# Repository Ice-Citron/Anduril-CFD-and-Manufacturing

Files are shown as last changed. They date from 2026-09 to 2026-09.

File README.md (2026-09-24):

# Anduril CFD and Manufacturing

**[ANDÚRIL RACING — Official team website](https://andurilracing.com/)**

[My personal commentary and project experience](https://sienarindustries.com/project/f1-in-schools)

Car designs, CAD exports, and supporting models for team ANDÚRIL RACING from Marlborough College Malaysia.

## Start here

These are the two main documents for this project. Read the project portfolio first.

1. [Project portfolio](PROJECT_PORTFOLIO.pdf) — Explains our contributions, design decisions, and build process. It covers the car and the wider team project.
2. [Technical drawings and renders](DRAWINGS_AND_RENDERS.pdf) — Shows the assembled car, dimensioned component drawings, and final renders.

*Louis Gan and Shi Hao Ng produced the project portfolio in Adobe Illustrator.*

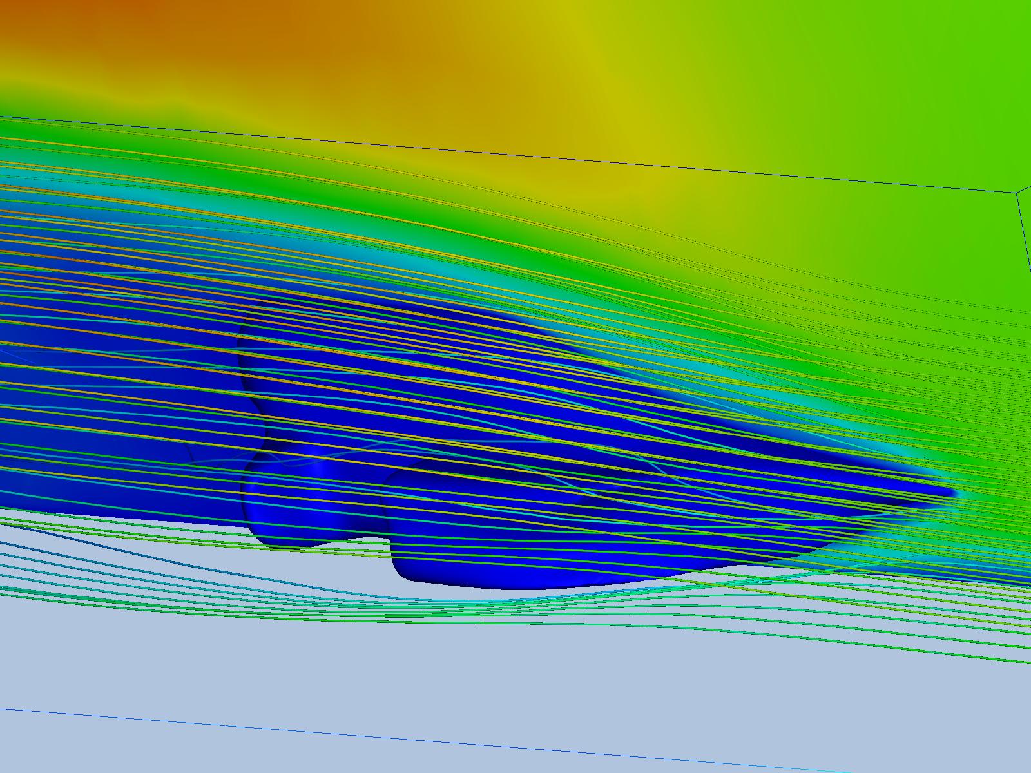
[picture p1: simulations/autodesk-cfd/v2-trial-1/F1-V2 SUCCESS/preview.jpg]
Airflow around the Version 2 car in Autodesk CFD


*Saved airflow visualisation from the Version 2 Autodesk CFD study.*

## About this repository

This repository contains the simulation and manufacture files for our F1 in Schools car. It follows the work from early geometry preparation to the Version 5 production exports.

The files cover three parts of the project:

- Computational fluid dynamics (CFD) studies.
- Geometry repair and conversion.
- Exports for CNC manufacture and resin print production.

The [Anduril Design repository](https://github.com/Ice-Citron/Anduril-Design) contains the wider design history. This includes the original Blender models and concept sketches.

## From a design to a physical car

Our team started with car models in Blender. We then prepared these models for CFD and manufacture.

This required several steps. We exported STL geometry from Blender and converted it to STEP format through Fusion 360. We used Ansys Discovery to prepare geometry for Fluent. More complex revisions also required mesh repair in Autodesk Netfabb.

The CFD work helped us examine airflow around the wheels and behind the car. We used these observations to develop the body shape and rear vanes.

Manufacture introduced further constraints. We had to consider component strength and the material available for the car body. The final work included separate exports for the CNC body and resin wings.

The project portfolio explains these decisions and the changes between car versions.

## CFD studies

The repository contains work from Autodesk CFD and Ansys Fluent.

| Study | Contents |
|---|---|
| [Version 2 Autodesk CFD trial](simulations/autodesk-cfd/v2-trial-1/) | Native project files, solver records, and saved output. Includes the airflow image above. |
| [Version 2 Fluent preparation](simulations/ansys-fluent/v2-preparation/) | Geometry exports and a Fluent session transcript. |
| [Version 2 UoSM study](simulations/ansys-fluent/v2-uosm-study/) | Ansys Discovery geometry, mesh files, and saved Fluent case and solution files. |

### Autodesk CFD

The Version 2 trial contains an Autodesk CFD 2024 project and its support files.

The main project is:

[Open the Autodesk CFD project file](<simulations/autodesk-cfd/v2-trial-1/F1-V2 SUCCESS/F1-V2 SUCCESS.cfdst>)

Its scenario folder contains mesh records and solver output. The saved preview provides a quick view of the airflow around the car.

### Ansys Fluent

The preparation folder records an early Fluent 2024 R1 session. It contains geometry preparation files rather than a saved case and solution pair.

The UoSM study contains the more complete simulation files:

- [Ansys Discovery model](simulations/ansys-fluent/v2-uosm-study/Discovery_File.dsco)
- [Mesh exports and workflow files](simulations/ansys-fluent/v2-uosm-study/Export/)
- [Fluent case and solution folder](<simulations/ansys-fluent/v2-uosm-study/Fluent/UoRM - Hypothesis/>)

The Fluent folder includes:

- `FSAE_Solution_Final.cas.h5`
- `FSAE_Solution_Final.dat.h5`

Earlier mesh attempts remain beside the later exports. These files show the geometry preparation work behind the study.

Some project files contain original Windows paths. You may need to update these paths in the relevant application.

## Geometry development

The `geometry/` folder contains intermediate models and exports for further analysis or manufacture.

| Folder | Contents |
|---|---|
| [Component variants: 2 mm](geometry/components-2mm/) | Rear-wing STL and OBJ files. |
| [Component variants: 3 mm](geometry/components-3mm/) | Wing and reference component meshes, including repaired exports. |
| [Version 3, trial 1](geometry/v3-trial-1/) | Three STL revisions from the Version 3 design. |
| [Version 4](geometry/v4/) | Body and component revisions, Netfabb projects, and STEP geometry. |
| [Version 5 CFD geometry](geometry/v5-cfd/) | STEP exports for the single-vane and double-vane configurations. |

The Version 5 comparison models are:

- [2 mm double-vane model](<geometry/v5-cfd/Version 5 - CFD 2mm double v0.step>)
- [3 mm single-vane model](<geometry/v5-cfd/Version 5 - CFD 3mm single v3.step>)

The internal filenames preserve the original revision labels.

## Manufacture

The `manufacturing/` folder contains files prepared for external suppliers and resin print production.

| Folder | Contents |
|---|---|
| [Version 4 CNC preparation](manufacturing/cnc/v4-fiverr/) | Body meshes and STEP exports from the earlier supplier work. |
| [Version 5 CNC exports](manufacturing/cnc/v5-fauzi-larkins/) | The Version 5 CNC STEP model and a body STL check export. |
| [Version 5 resin print exports](manufacturing/resin-print/v5/) | Body and wing STL files, including separate front-wing and rear-wing models. |

[View the Version 5 CNC model](<manufacturing/cnc/v5-fauzi-larkins/Version 5 - CNC v5.step>)

Nosco Asia helped us work with a CNC supplier in Larkin, Johor Bahru. Our team supported the CAM preparation through Mastercam and Fusion 360.

The University of Southampton Malaysia provided resin print facilities for the front and rear wings. The project portfolio records the subsequent assembly and surface finish work.

## My contribution and the team

I am Shi Hao Ng. I was the project manager and general engineer for ANDÚRIL RACING.

I led the technical work on CFD and car design. I also coordinated external support and managed the track manufacture work.

This was a team project. The portfolio records the following roles:

| Team member | Main responsibilities |
|---|---|
| Shi Hao Ng | Project management, technical direction for CFD and car design, and track manufacture coordination. |
| Louis Gan | Electronics, the track timer system, and graphic design. |
| Samson Hong | CAD models, car manufacture, and Blender renders and animation. |
| Jolie Teo | The team website, graphics, and support for manufacture and sponsorship. |
| Hengjun Tian | Ansys Fluent studies and track manufacture. |
| Jane Ng | Car concept art and sponsor relations. |

The University of Southampton Malaysia supported the CFD work and resin production. Nosco Asia supported CNC manufacture. Marlborough College Malaysia supported the wider project and track construction.

## Repository structure

```text
Anduril-CFD-and-Manufacturing/
├── README.md
├── PROJECT_PORTFOLIO.pdf
├── DRAWINGS_AND_RENDERS.pdf
├── LICENSE
├── simulations/
│   ├── autodesk-cfd/
│   │   └── v2-trial-1/
│   └── ansys-fluent/
│       ├── v2-preparation/
│       └── v2-uosm-study/
├── geometry/
│   ├── components-2mm/
│   ├── components-3mm/
│   ├── v3-trial-1/
│   ├── v4/
│   └── v5-cfd/
└── manufacturing/
    ├── cnc/
    │   ├── v4-fiverr/
    │   └── v5-fauzi-larkins/
    └── resin-print/
        └── v5/
```

## Related repositories

- [Anduril](https://github.com/Ice-Citron/anduril) — Main project repository, team website source, and sponsorship documents.
- [Anduril Design](https://github.com/Ice-Citron/Anduril-Design) — Original design files, concept sketches, and models for the car and track.

## Licence

This repository uses the [MIT License](LICENSE).

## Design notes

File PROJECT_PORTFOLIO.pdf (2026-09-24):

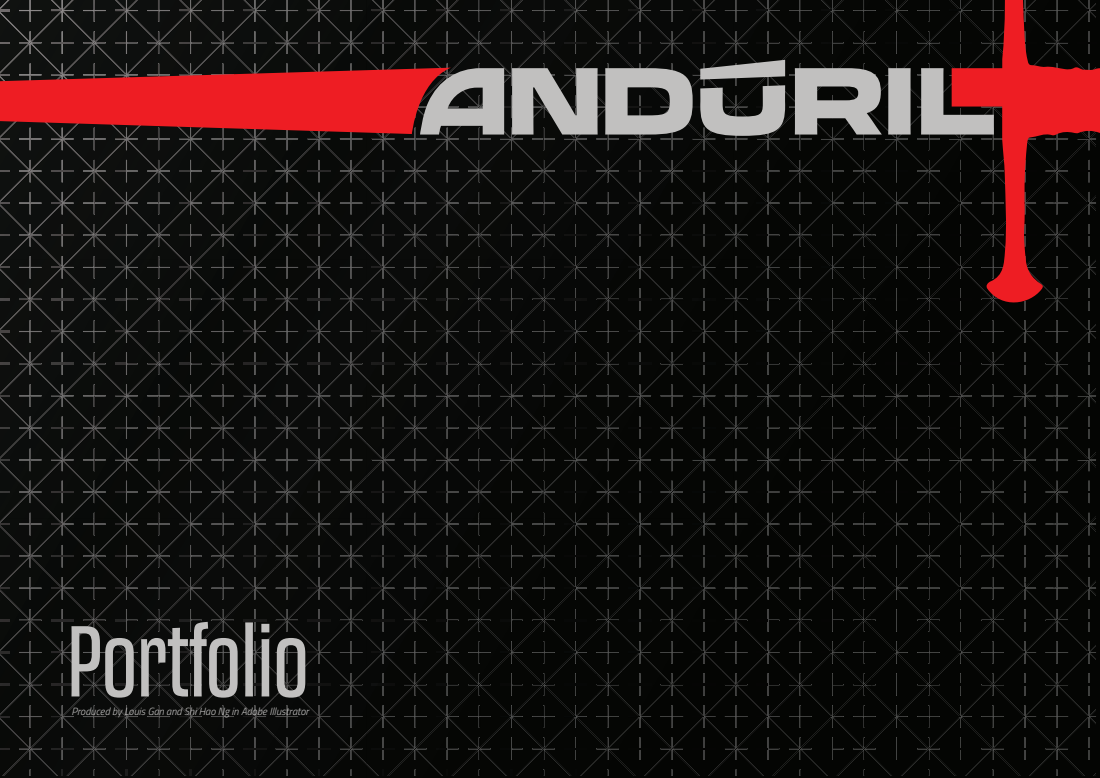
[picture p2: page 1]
Portfolio

Produced by Louis Gan and Shi Hao Ng in Adobe Illustrator

# Research and Development Workflow

Our journey began with Samson and Jane crafting the initial car designs using Blender. Although Blender is primarily an animation software, we chose it for our main CAD modeling due to our team's familiarity with the platform and its ease in translating our concept art into 3D models. These early versions (v1 & v2) were rich in creativity and aesthetics but lacked consideration for the competition's no-go zones and model block size specifications.

# 1 Sketches

With our initial models ready, we proceeded to CFD testing using Ansys Fluent, assisted by University of Southampton Malaysia. Since CFD software requires meshable models, we exported our Blender designs as STL files and converted them to STEP files using the T-Spline function in Fusion 360. These STEP files were then imported into Ansys Discovery for preparation before running simulations in Ansys Fluent. The simulations applied an inlet velocity of 30 m/s and an angular velocity of 2000 rad/s for all 4 wheels to mimic race conditions.

In Version 4, we maintained the long tail design but became more rigorous with regulatory compliance. To meet the no-go zone regulations, we adjusted the entire car forward, allowing us to retain the tail at the car's end while complying with the rules. We meticulously ensured that all aspects of the car met the regulatory requirements.

However, we strategically decided to accept a 5-point penalty related to the front wing chord length (Rule D7.9). Redesigning the front section to comply fully would have resulted in a structurally weaker and less aesthetically pleasing front wing. We deemed the penalty acceptable to maintain the integrity and performance of our design. Most importantly, we ensured that the front wing did not obstruct any other components of the car (e.g. main body).
Due to the increased complexity of Version 4 compared to Version 2, we needed to remesh the STL file using Autodesk Netfabb before converting it to a STEP file with Fusion 360's T-Spline function.

The analysis revealed several weaknesses:
1. Airflow into Wheels: Contour path lines indicated that airflow tended to enter the wheels, creating significant drag. Our per-component analysis showed that the front wing contributed to 70% of the total drag (47.68 mN). Additionally, the wheels, spinning at 2000 rad/s, exacerbated drag due to air bouncing around them.
2. Iso-Pressure Zones: These zones indicated inefficiencies in airflow around the car body, particularly due to the wake of the car. Notable iso-pressure zones were observed behind the front wing, behind the front wheels, and especially at the rear of the car.

Iso-Pressure Zones: These zones (graphed out in image above) indicated inefficiencies in airflow around the car body, particularly due to the wake of the car. Notable iso-pressure zones were observed behind the front wing, behind the front wheels, and especially at the rear of the car.

# 2 Transition to CFD Analysis

# 3 Design Iterations: Version 3

We also introduced air vanes (diverters) to direct airflow to the low-pressure recirculation zone in the rear middle of the car, further minimising turbulence. Concept art for Version 3 was created, showcasing the long tail design and the coverage of both front and rear wheels as much as regulations allowed. We then utilised this concept art directly within Blender to assist in the modelling process.

To address these issues, we focused on minimising the wheels' exposure to airflow. Inspired by the tail design of the McLaren Speedtail, we incorporated a longer tail with a gradual slope behind the rear wheels. This aimed to even out the airflow, reducing turbulence by allowing air to fill the area more gradually, thereby reducing iso-pressure zones at the rear.

Using concept art within Blender to assist in modelling

# 3 Adhering to Regulations: Version 3 Onwards

From Version 3 onwards, we began factoring in the actual model block and no-go zones as specified by the competition rules. We ensured that the front wheels were covered up to a maximum of 20 mm from the bottom of the track and maintained a 3 mm exclusion zone around the wheels, as per the regulations.

To meet no-go zone regulations, we pushed the entire car forward to retain the tail

# Manufacturing

To save money for our school from buying the official expensive Denford Webshop equipments. We took on the ambitious task of manufacturing our own gas launcher, track timer system, and a 20-meter racing track to simulate race conditions accurately.

Our gas launcher was 3D-printed using PLA material, following a design courtesy of @TeachingTech on Printables.com. Key features of the gas launcher include:
- High-Tension Springs: Ensure rapid activation and consistent propulsion of the car.
- Sharpened Screw: Acts as a puncture mechanism for the CO₂ canisters.
- Electric Solenoid Integration: Allows for electronic control through the press of a button, providing precise timing and synchronisation with the timing system (mimicking the official Denford system). After assembly and testing, the gas launcher performed successfully, meeting our requirements for race simulations.

# Gas Launcher

Once the main body and front wing are finalised, we worked on the rear wing. The rear wing was designed primarily for aesthetic purposes and to comply with competition regulations, as additional downforce was unnecessary for a straight-line race. The rear wing features a flat profile cross-section and complements the overall design of the car.
Finally, we sent our finalised design files to Nosco Asia for CNC machining. Concurrently, we used resin printers at UoSM to produce components like the front and rear wings.

We constructed a 20-metre track using pine wood through the following steps:
1. Design: Sketched and designed the track layout in Blender for ease of manufacturing and coordination with the Estates team.
2. Cutting & Sanding: Cut pine wood to required dimensions using a jigsaw and table saw, then sanded with orbital sanders while wearing safety goggles and aprons.
3. Track Connectors: Fabricated joints by modifying stainless steel brackets to securely connect track segments, ensuring safety gear was worn.
4. Assembly: Applied adhesive to join track sections and collaborated with Marlborough College Malaysia’s Estates team to carry and assemble the track and tables.
With assistance from the Estates team, we assembled the track and tables in our designated testing area, repurposing unused old tables from MCM to promote sustainability.
Finishing Touches
We painted the pinewood track to enhance its appearance and protect against Malaysia's humid conditions. Custom decals were added to personalize the track and promote our team branding.

# 20m Track

To accurately measure the performance of our car, our Electronics Engineer prefabricated a track timer system using an Arduino microcontroller paired with laser sensors and photoreceptors. The system was programmed in C++, enabling precise detection of the car's start and finish times, thus allowing us to gather essential data on speed and acceleration.

# Track Timer System

Nosco Asia facilitated our collaboration with a third-party CNC machining service in Larkin, Johor Bahru. Working closely with their team, we built the CAM file based on the STEP file of our final car design.

- CNC Machining: Precisely
cutting the car's body from
the specified material using computer-controlled
equipment. We’ve assisted
the 3rd party provider
“Sticker Shop@Larkins, JB” with Mastercam and
Fusion 360. To guide him
with the process of
machining our car.
- Sanding: Post-machining, we sanded the car's
surface to eliminate any
rough edges or
imperfections.

# 4 Car Manufacturing Final CFD Testing and Improvements

We conducted further CFD tests using the same setup as before. The results showed a significant reduction in drag:
- Version 2 Drag: 47.68 mN
- Version 4 Drag: 29.52 mN (single vane diffuser)
- Version 4 Drag: 30.36 mN (double vane diffuser)
These CFDs conducted using the Comsol fluid modulus indicate a substantial reduction in turbulence. The side profile of the air velocity graphs confirmed that our design modifications effectively minimised turbulence compared to Version 2.

Initially, we designed a triple vane rear diffuser, but material constraints and potential airflow disruptions limited us to single and double vane configurations. A double vane design required vanes only 20mm thick, risking breakage with our polyurethane car body. To mitigate this, we opted for a single vane diffuser with a 30mm thickness for Version 5. Once the design was finalized, we prepared the files for CNC machining and began designing the rear wing.

Cross-sectional profile of Rear Wing

<--- Final Version 5 car with rear wing

Mastercam software. We guided the 3rd party Nosco Asia’s CNC provider over Whatsapp on how to CNC our car, and the
requirements.
- 3D printed front wing: We’ve used the resin printers of University of Southampton to facilitate the printing of our front wings and rear wings.
- Assembly: We’ve used adhesives to attach components such as the front and rear wings.
- Final Painting and Sticker: The car is then spray painted to metallic black. However, applying the sticker will be an outstanding task, as of 2/10/2024. But we will be applying our team colours and sponsorship stickers to align with our branding.
Through this meticulous process, we aimed to produce a car that not only meets the competition's technical specifications but also embodies our team's dedication to excellence in engineering and aesthetics.

Priming and Painting: To prepare the car for painting, we applied six layers of primer, meticulously alternating between spraying and sanding each layer. This iterative process ensured a smooth surface that minimizes the drag coefficient, providing an ideal foundation for the final paint.

# Team Roles & Responsibilities

Project Management
Effective communication and coordination are the backbone of our project management strategy. While each team member has clearly defined roles, flexibility is maintained as members step into different responsibilities when needed to ensure smooth progress and efficiency.
Google Drive: Acts as our centralized repository for all documents, facilitating real-time collaboration and easy access for every team member.
GitHub: Utilized for storing larger files such as CAD models and website code, ensuring robust version control and seamless updates.
Emails: Serve as the primary method for assigning tasks, sharing detailed information, and communicating daily goals. Instant Messaging (Instagram Messages): Preferred during holidays for quick communication. During regular school days, we alternate between Instagram messages and emails based on accessibility and convenience.
Instagram Calls: Employed for emergency meetings and real-time collaboration, especially when team members are working remotely.

Name Background
Our team name, Andúril, is inspired by the legendary sword from The Lord of the Rings. Reforged from the shards of Narsil, Andúril symbolises hope, renewal, and leadership in times of adversity. It serves as a powerful emblem of unity and strength, reflecting our team’s commitment to overcoming challenges and striving for excellence.
Colours
We selected a palette of red, silver, and black to represent our team:
Red: Symbolises passion, energy, and speed, embodying the core values of Formula 1. Silver: Represents precision, technical excellence, and innovation, highlighting our engineering prowess.
Black: Adds contrast and sophistication, enhancing the overall aesthetic of our design. These colours were chosen based on extensive research and a team-wide questionnaire, ensuring they resonate well with our brand and are visually appealing. Team Motto
"Per Aspera Ad Astra"
Our team’s motto, "Per Aspera Ad Astra," embodies the essence of our journey and aspirations in the F1 in Schools competition. This Latin phrase translates to "Through Hardships to the Stars," reflecting our commitment to overcoming challenges and striving for excellence in every aspect of our project.
Uniform
Our team uniforms are designed to showcase both unity and our brand identity. Key considerations in the design include:
Clear and Memorable Branding: Ensures our team is easily identifiable. Professional Appearance: Reflects our values of excellence and dedication. Strategic Placement of Sponsor Logos: Guarantees visibility and return on investment for our sponsors. Comfort and Suitability: Designed to be worn comfortably in Malaysia’s humid climate, ensuring team members can perform optimally.

Gantt Charts (Google Sheets): Used to outline task expectations and deadlines, providing a clear timeline and efficient progress tracking. Our Gantt Charts include:
Job Descriptions: Clearly define each task and responsibility.
Job Status: Track the progress of each task.
Time Remaining: Monitor deadlines to ensure timely completion. Potential Safety Risks: Identify necessary Personal Protective Equipment (PPE) for each task. Risk of Timeline Delays: Assess the likelihood of delays and prepare backup plans. For example, on October 2, 2024, when Jolie fell ill last minute, causing a portfolio submission delay, we activated our backup plan by adjusting our schedule the following day to accommodate the change.
Expense Tracking (Excel Sheets): Managed all expenses and finances using Excel sheets, ensuring transparent and accurate financial oversight.

In-Person
Meetings:
Conducted for
group work and
tackling complex
tasks, leveraging
the productivity
and clarity of
face-to-face
interactions.

### Our team, Andúril Racing, is composed of six dedicated members, each bringing unique skills to the table:

### Shi Hao Ng: Project Manager & General Engineer –

Oversees project coordination with all stakeholders,

### technical lead for CFD and car design, and manages

track manufacturing tasks.

### Louis Gan: Electronics Engineer & Lead Graphic Designer – Designer for brand identity such as logos, merchandise and banners, and develops

electronic systems for testing the car.

### Samson Hong: Design Engineer – Leads the car manufacturing and CAD modelling process, and

ensures high quality Blender animation & rendering.

### Jolie Teo: Web Designer & Graphics Designer – Develops and maintains our team’s website and creates graphics materials, also assisting in

manufacturing and sponsorships.

### Hengjun Tian: CFD Engineer & Manufacturer – Conducts Computational Fluid Dynamics (CFD) with Ansys Fluent and implements the track

manufacturing process.

### Jane Ng: Concept Artist & Sponsorship Manager – Creates concept art for car and manages

sponsorship outreach and relationships.

# About Us

Emails: The project manager often Team Identity reaches out to teammates to

distribute work and to communicate
what each member should get done
for the day.
We purchased custom email domains for our team for a streamlined electronic mail experience as well as a professional look when sending sponsorship requests via email. Typography
Our chosen font, Transducer Extended Bold, conveys
confidence and power. Its
streamlined design mirrors the sleek form of Formula 1 cars, emphasising precision and high-tech performance. The metallic texture of the font enhances its high-tech, engineered aesthetic,
aligning seamlessly with the advanced dynamics of
racing.
The Andúril logo features
the team name seamlessly
integrated along a sword
blade, symbolising the unity between our team and its
legendary inspiration.

# Partnership and Sponsorship

Our partnership with the University of Southampton Malaysia allowed us to use their program “Ansys Fluent” to test our F1 in car’s model’s movement and design. Their research assistance not only helped us save funds but also time. They had also provided us with resin printing equipment, which helped our production of the actual car.

## Return on Investment

We have laid a strong foundation for future participants in F1 in Schools, not just at MCM, but in Johor. By building our own track, gas launcher and electronics timer system, we saved the school approximatelyMYR 42,000, excluding 30% import duties and taxes. Considering their sponsorship of just MYR 6,000, this is a substantial return on investment for Marlborough College Malaysia. Most importantly, we firmly believe that, because of us, because of our manufacturing of the track, gas launcher, and track timer system. We had laid out a
strong foundation for many future teams from MCM
to join the F1 in Schools programme.

Nosco Asia Sdn Bhd played a crucial role in our manufacturing and marketing strategies. They facilitated our collaboration with a CNC machining service in Larkin, Johor Bahru, ensuring precise production of our car components. Nosco Asia also provided banner printing services and transportation support, which significantly boosted our marketing efforts and outreach campaigns. They had sponsored us 3,200 MYR for the banner printing and the CNC machining services.

We worked on the business aspects with UoRM and most of these include the sponsorship proposal. Although our sponsorship proposal wasn’t as successful as we wished for it to be (as we only managed to receive Nosco Asia’s support), we wish to flesh it out further and try out a different technique for the nationals. They had also helped us with project management after advising our project manager to try “Gantt Chart” to distribute tasks and communicate deadlines; and dealing with issues such as conflict between team members; also when we were forced to remove a member due to the severe lack of contribution.

Our school, Marlborough College Malaysia (MCM), has been our main sponsor for all of our respective expenses of up to 6k MYR. MCM supported us in many different ways, including providing old desks for our track, allocating estate staff to assist in track manufacturing and moving equipment from one building to another. MCM also allowed us to display banners across the school to advertise. In return, we built a race track and an efficient timing system which is open to any schools established in Johor (to encourage new F1 in schools participants in Johor). Additionally, by reusing desks that were set to be scrapped, we contributed to reducing waste and reusing materials.

To enhance our design's aerodynamic efficiency, we attended courses with Professor Azam Bakir at the University of Southampton Malaysia (UoSM). These sessions provided a foundational understanding of the Navier-Stokes equations and fluid dynamics principles. Recognizing that solving Computational Fluid Dynamics (CFD) simulations analytically is impractical for complex designs, we agreed with Professor Bakir's assessment to focus on computational methods and fluid flow theories. Concepts such as how holes lead to suction and how low-pressure zones lead to turbulence became central to our design considerations.

YOUR
LOGO
HERE

AD
PLACE
MENT

COMPANY
PARTNERSHIP

YOUR
LOGO
HERE

AD
PLACE
MENT

COMPANY
PARTNERSHIP

We have also created a website summarising details regarding our team members, summarising our sponsors and answering any questions regarding F1 in schools and our team.
We felt that creating a website can create memorable credentials with companies and schools who may wish to sponsor us but are confused as to what Anduril Racing stands for.

Our social media endeavours ranged from Instagram, later to Linkedin (to establish a professional identity for Anduril Racing) and lastly, Facebook. Our strategy begins with reaching out to familiar faces : we followed familiar people such as our family members, then our relatives, schoolmates and lastly, accounts that are associated with f1. We can help to build awareness on Anduril Racing’s participation in F1 in schools and hence potentially gain partnerships. Social media was also a great way of allowing our partners to keep track of Anduril Racing’s activities and recent goals.

To advertise Anduril Racing, three of our members went on to hike Mount KInabalu and spread the word regarding Anduril Racing’s participation in the competition (to different hikers that we met along the way). Many of our fellow hikers still check on our Instagram till this day.

# ခandurilracing.com

## Mount Kinabalu Teambuilding & Mountain Climbing Trip (4095m)

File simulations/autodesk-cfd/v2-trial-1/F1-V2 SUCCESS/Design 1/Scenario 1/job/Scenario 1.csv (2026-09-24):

CPU time | 35.804
memory | 200450048
fluid nodes | 74332
solid nodes | 9256
fluid elements | 211266
solid elements | 75956

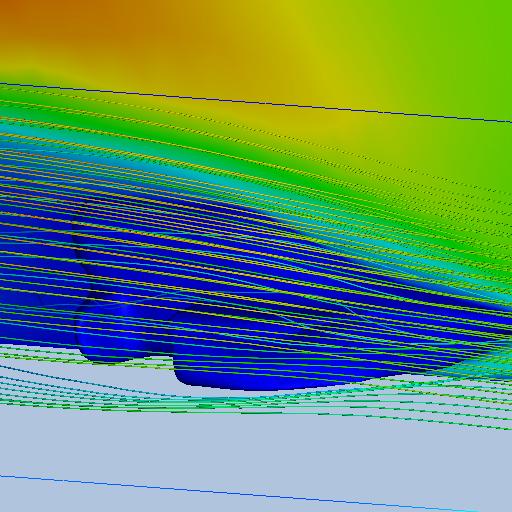
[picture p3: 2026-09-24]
simulations/autodesk-cfd/v2-trial-1/F1-V2 SUCCESS/Design 1/Scenario 1/thumbnail.jpg

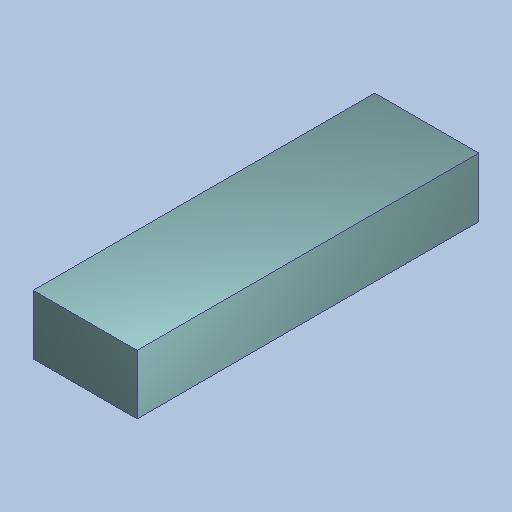
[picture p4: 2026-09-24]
simulations/autodesk-cfd/v2-trial-1/F1-V2 SUCCESS_support/Design 1/Scenario 1/thumbnail.jpg

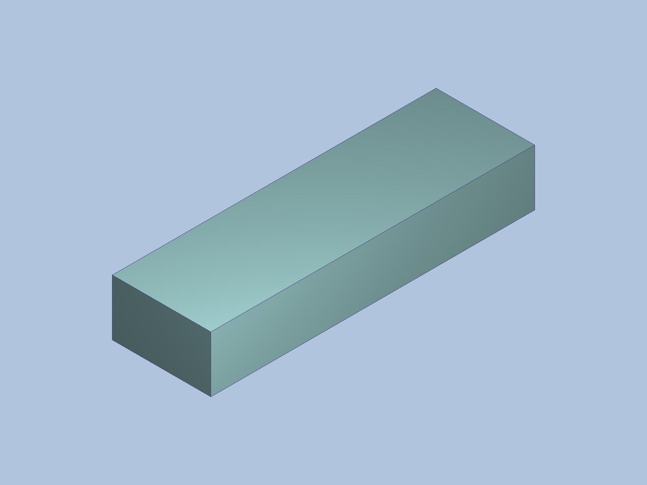
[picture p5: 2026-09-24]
simulations/autodesk-cfd/v2-trial-1/F1-V2 SUCCESS_support/preview.jpg

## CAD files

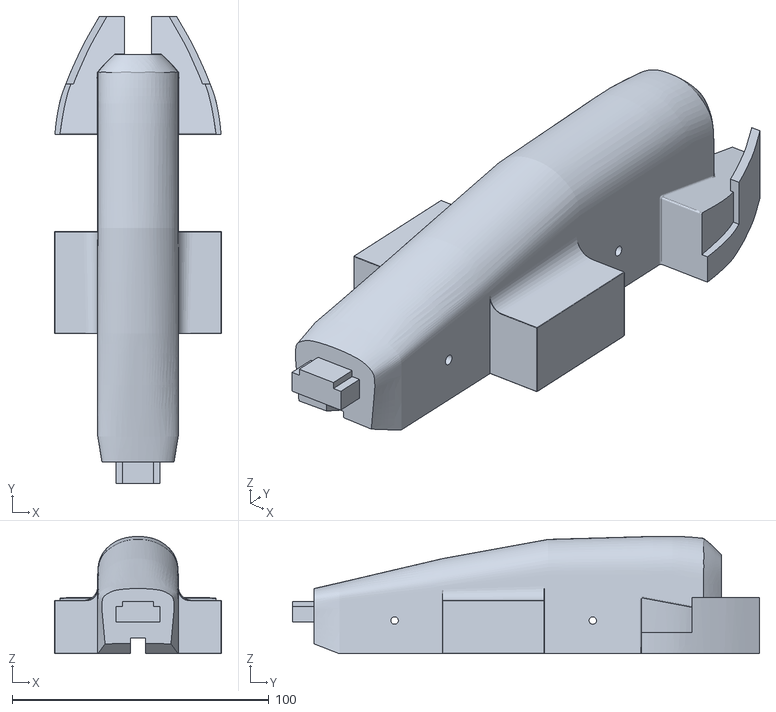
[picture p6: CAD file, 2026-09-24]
manufacturing/resin-print/v5/MAIN_Body1.stl
65.0 x 181.9 x 45.6

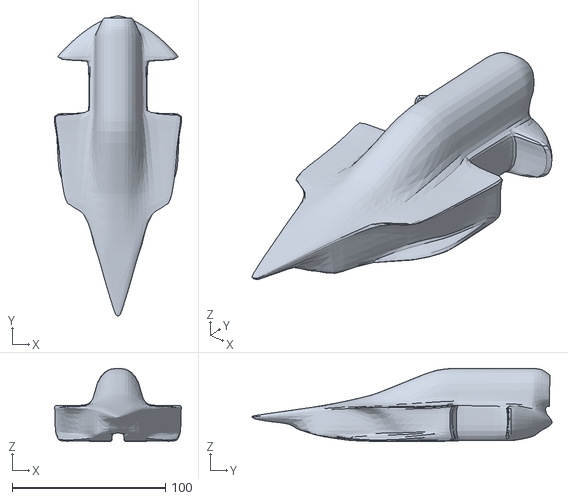
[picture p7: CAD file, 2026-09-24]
simulations/autodesk-cfd/v2-trial-1/Ver-2-new-ASSEMBLE BODY.stl
83.0 x 195.8 x 47.7

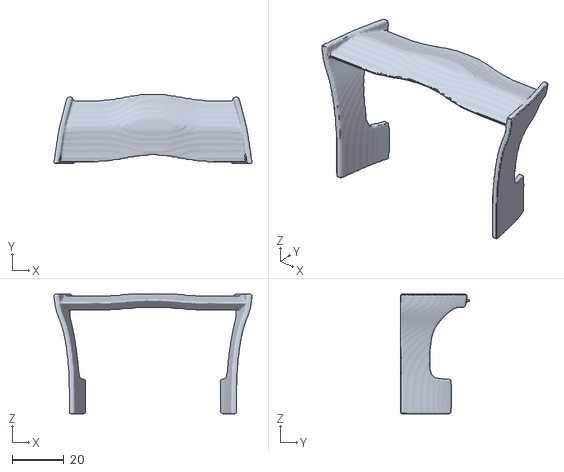
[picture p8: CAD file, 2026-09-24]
geometry/components-2mm/2mm - Blueprint and STL-Rear Wing - flaps.005 (manipulated).obj
76.8 x 26.9 x 46.5

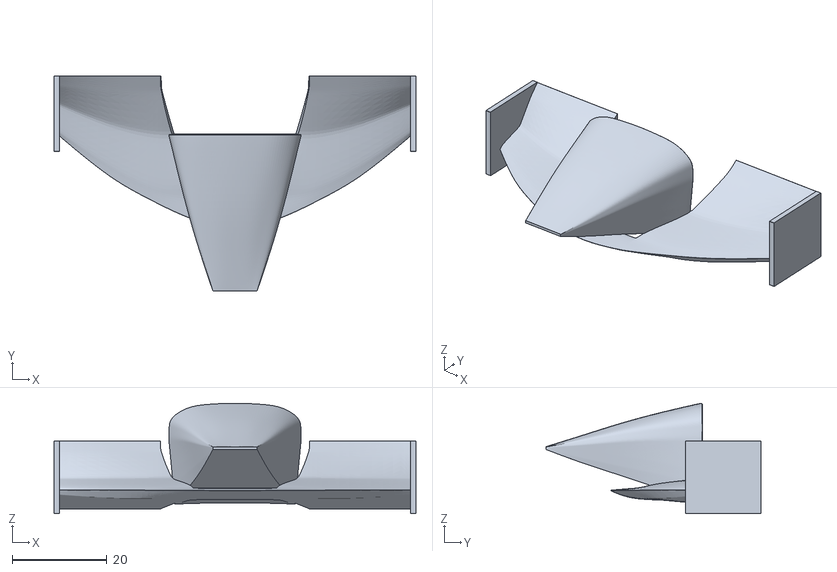
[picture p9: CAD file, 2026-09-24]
geometry/components-3mm/Blueprint and STL-FRONT WING Version 3.008.stl
76.5 x 45.5 x 23.3

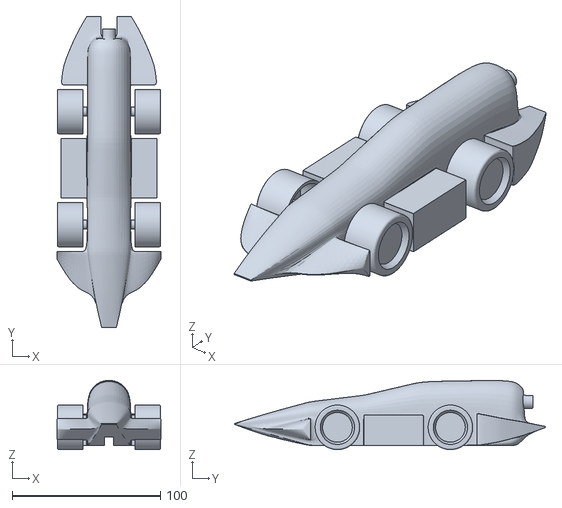
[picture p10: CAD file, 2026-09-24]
geometry/v3-trial-1/Version 3 - Louis-Version 3.006.stl
70.3 x 209.5 x 46.6

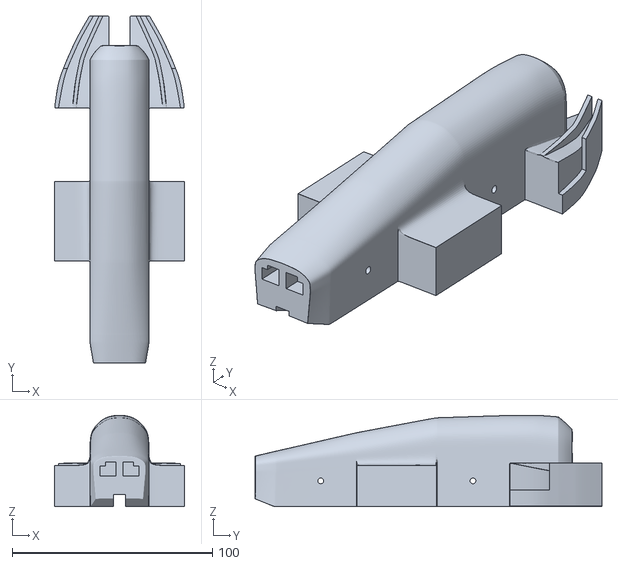
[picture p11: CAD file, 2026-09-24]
geometry/v4/AAA - MAIN STEP CNC/Version 4 - Print-Version 3.003.stl
65.0 x 173.4 x 45.6

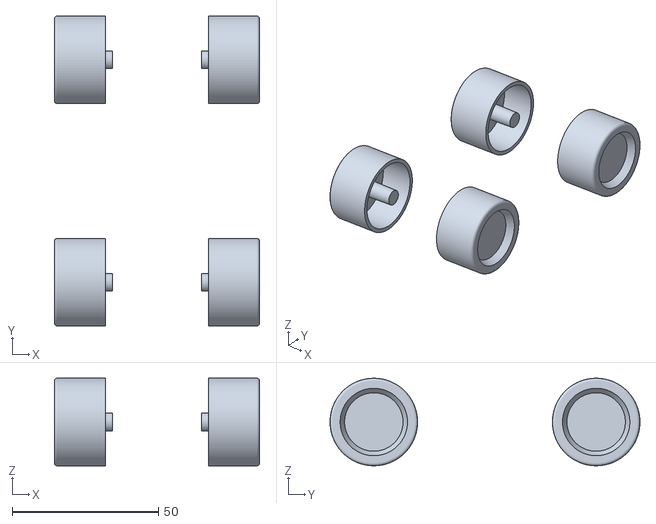
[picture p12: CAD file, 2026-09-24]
geometry/v4/Boolean + Wheels 2/Version 3 - Latest-f1_wheel.002.stl
70.3 x 106.1 x 30.0

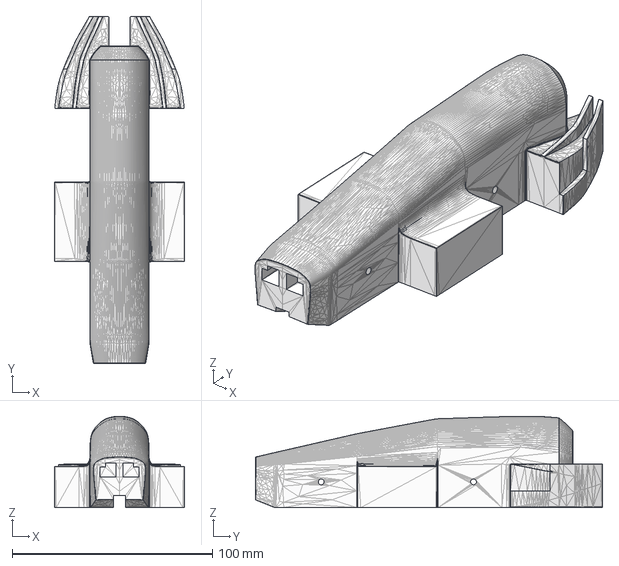
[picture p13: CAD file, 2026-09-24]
geometry/v4/Solidwork Source/SOLID1.STEP
65.0 x 173.4 x 45.6 mm

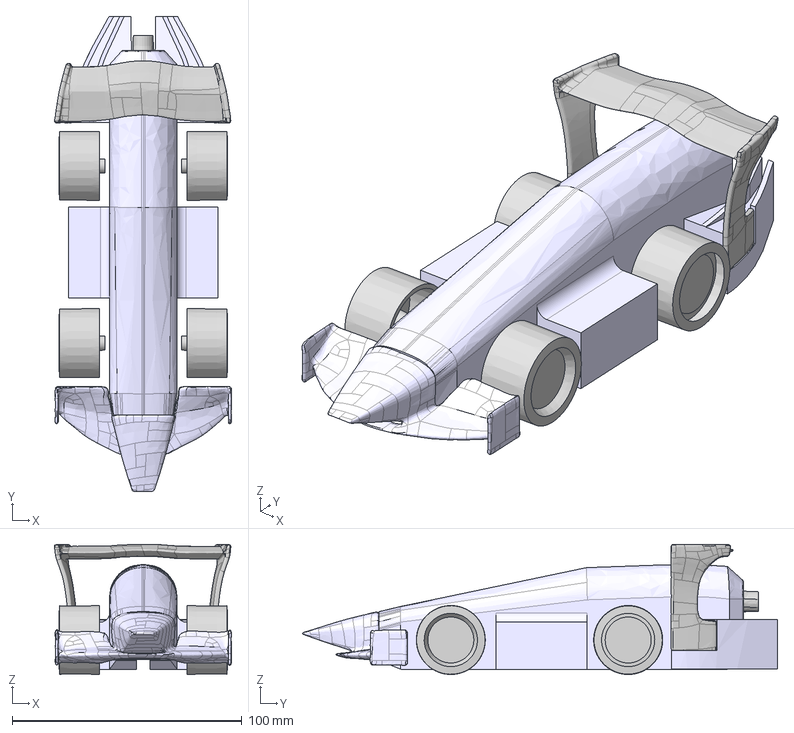
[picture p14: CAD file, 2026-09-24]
geometry/v5-cfd/Version 5 - CFD 2mm double v0.step
77.0 x 206.6 x 56.6 mm

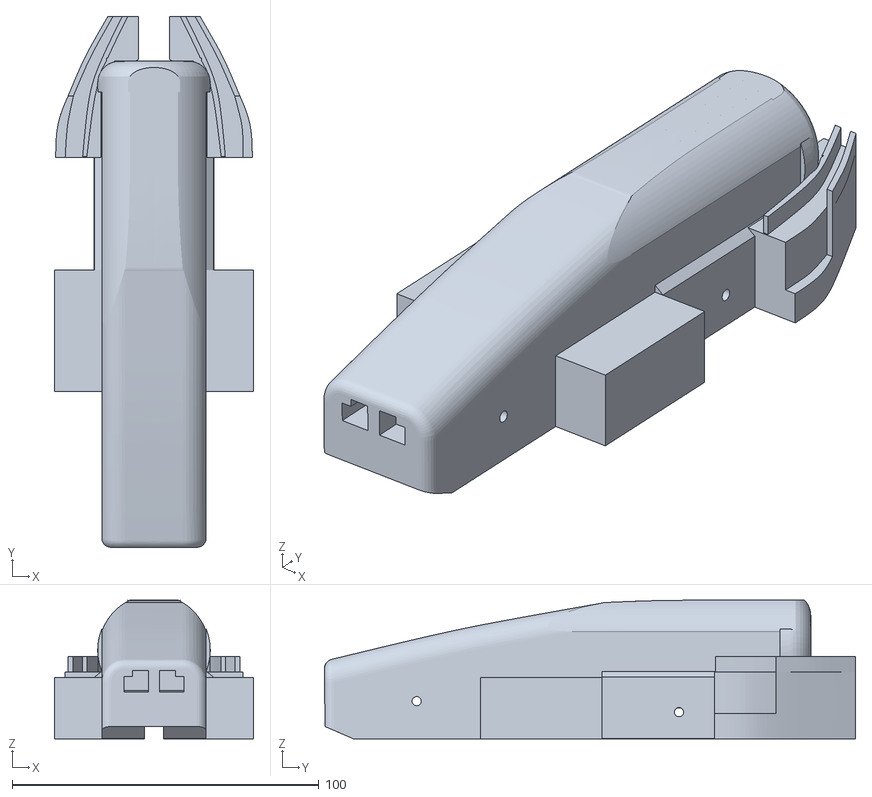
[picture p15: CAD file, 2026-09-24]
manufacturing/cnc/v4-fiverr/Body1.stl
65.0 x 173.1 x 45.2

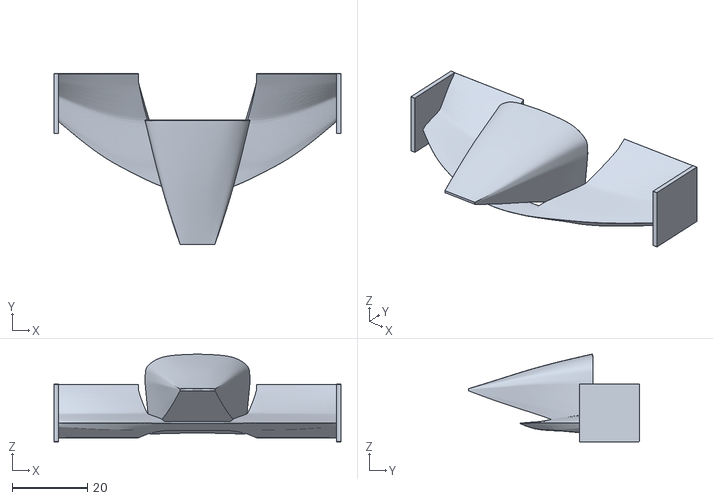
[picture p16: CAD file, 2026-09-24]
manufacturing/resin-print/v5/Resin Print/Blueprint and STL-FRONT WING Version 3.011.stl
76.5 x 45.5 x 23.3

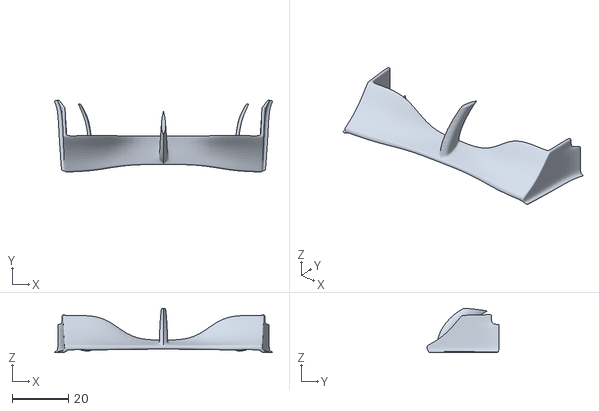
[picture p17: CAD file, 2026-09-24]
simulations/ansys-fluent/v2-preparation/Ver. 2-Front Wing.stl
77.7 x 25.6 x 15.8

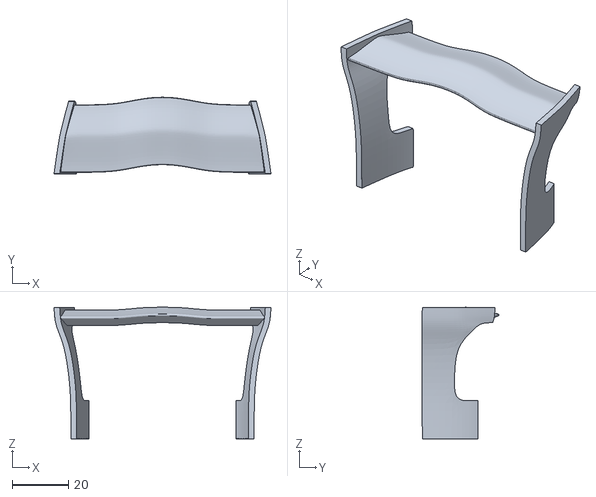
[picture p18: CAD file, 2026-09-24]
geometry/components-2mm/2mm - Blueprint and STL-Rear Wing - flaps.005.stl
77.0 x 27.2 x 46.7

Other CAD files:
simulations/ansys-fluent/v2-preparation/Ver. 2-ASSEMBLE BODY.stl
manufacturing/cnc/v4-fiverr/FINAL/Version 4 - Print-Version 3.003.1 v3.step
manufacturing/cnc/v4-fiverr/Fiverr T2/Version 4 - STEP.stl
manufacturing/cnc/v5-fauzi-larkins/Version 5 - CNC v5.step
geometry/components-3mm/Blueprint and STL-FRONT WING Version 3.008 (repaired) (repaired) (manipulated).obj
geometry/components-3mm/Blueprint and STL-Rear Wing - flaps.010 (manipulated).obj
geometry/components-3mm/Blueprint and STL-Rear Wing - flaps.010.stl
geometry/components-3mm/Blueprint and STL-f1_wheel.010.stl
geometry/components-3mm/Blueprint and STL-f1co2std___f1co2cmp.010.stl
geometry/v3-trial-1/Version 3 - Louis-Version 3.004.stl
geometry/v3-trial-1/Version 3 - Louis-Version 3.005.stl
geometry/v4/Archive - September 6/B+W/B+W - Latest-FRONT WING Version 3.001.stl
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
